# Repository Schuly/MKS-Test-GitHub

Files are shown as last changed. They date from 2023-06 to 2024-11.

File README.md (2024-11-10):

Inhaltsverzeichnis

# Inhaltsverzeichnis

1. **Hardware List**
    - [Motor](https://github.com/Schuly/MKS-Test-GitHub/tree/main/1%20Motorisierung)
    - [Platzhalter Unterpunkt 2](#)
2. **History**
    1. **Motorization**
        - [Platzhalter Unterpunkt 1](#)
        - [Platzhalter Unterpunkt 2](#)
    2. **Energy & Sensors**
        - [Platzhalter Unterpunkt 1](#)
        - [Platzhalter Unterpunkt 2](#)
    3. **Obstacle Race**
        - [Platzhalter Unterpunkt 1](#)
        - [Platzhalter Unterpunkt 2](#)
    4. **Photos**
        - [Platzhalter Unterpunkt 1](#)
        - [Platzhalter Unterpunkt 2](#)
    5. **Videos**
        - [Platzhalter Unterpunkt 1](#)
        - [Platzhalter Unterpunkt 2](#)
3. **.DS_Store**
4. **a. 3D Printing**
    - [Platzhalter Unterpunkt 1](#)
    - [Platzhalter Unterpunkt 2](#)
5. **b. Diagrams**
    - [Platzhalter Unterpunkt 1](#)
    - [Platzhalter Unterpunkt 2](#)
6. **c. Circuit Diagram**
    - [Platzhalter Unterpunkt 1](#)
    - [Platzhalter Unterpunkt 2](#)
7. **d. Code**
    - [Platzhalter Unterpunkt 1](#)
    - [Platzhalter Unterpunkt 2](#)
8. **e. Construction Manual**
    - [Platzhalter Unterpunkt 1](#)
    - [Platzhalter Unterpunkt 2](#)
9. **f. Other**
    - [Platzhalter Unterpunkt 1](#)
    - [Platzhalter Unterpunkt 2](#)

# Team MKS Robotics

**Infos zum Githubaufbau**

Unsere GitHub Dokumentation ist entsprechend dem Webertungsbogen der WRO Future Engineers Kategorie aufgebaut. Unter Punkt 1-5 sind die 
Informationen und das Material entsprechung der Bewertungskriterien vorhanden. 
Darunter under Punkt a-f findest man sonstige Sachen, die unsserer Meinung nach auch wichtig sind.

**Einleitung**

Wir sind Nico und Julian aus dem Saarland und nehmen dieses Jahr erneut für die Maximilian-Kolbe-Schule Wiebelskirchen an der WRO-Kategorie Future-Engineers teil. Im letzten Jahr haben wir bereits erfolgreich teilgenommen und den ersten Platz im Vorentscheid in Waldkirch/Freiburg belegt. Dadurch haben wir uns für das Deutschland-Finale in Chemnitz qualifiziert, wo wir den 4. Platz erreicht haben. Darüber hinaus haben wir bereits an vielen anderen Wettbewerben teilgenommen, darunter die "Robonight" in Saarbrücken, wo wir zweimal den zweiten Platz belegt haben, und die "make-it", wo wir den ersten Platz erreicht haben. Alles begann jedoch mit der WRO, bei der wir im Jahr 2019 in der Kategorie „Mission“ erstmals teilgenommen haben.

**Programmierung Eröffnungsrennen**

Beim diesjährigen Eröffnungsrennen verwenden wir die Grundidee vom letzten Jahr. Während der Fahrt misst der Roboter kontinuierlich die Werte der Ultraschallsensoren, die vorne, links und rechts angeordnet sind. Basierend auf den Werten des linken und rechten Sensors berechnet der Roboter den Mittelpunkt und steuert das autonome Auto proportional, um sich bestmöglich wieder in die Mitte zu bringen. Das bedeutet, je weiter das Auto von der Mitte entfernt ist, desto mehr lenkt es, um diese Mitte wieder zu erreichen.

Ein Beispiel: linker Ultraschallsensor: 10, rechter Ultraschallsensor: 50. Hier zeigt der linke Sensor eine sehr kurze Entfernung, was bedeutet, dass das Auto ziemlich weit links an der Bande ist. Wenn wir nun die Summe der beiden Werte nehmen, ergibt sich die Zahl 60. Die Hälfte davon ist 30. Wenn beide Sensoren nun den Wert 30 ausgeben, wissen wir, dass der Roboter genau in der Mitte ist. Um diese Mitte zu erreichen, berechnen wir den Prozentanteil und lenken entsprechend.

Da dieser Prozess sehr schnell und sehr oft wiederholt wird, kann es manchmal zu einem leichten Schwanken kommen, das das Auto aber ausgleicht. Um am Ende der 3 Runden perfekt zu stoppen, zählt das Auto eine Variable hoch, wenn es eine Kurve fährt. Wir erkennen eine Kurve, wenn plötzlich ein Sensor einen sehr hohen Wert misst. Wenn wir also wie im Beispiel eine Summe von 60 haben und einer der Sensoren plötzlich 150 misst, können wir sicher sein, dass wir uns in einer Kurve befinden. Wenn der Roboter dies 12-mal erkannt hat, bleibt das Auto im richtigen Abschnitt stehen.

**Programmierung Hindernisrennen**

Bei dem Hindernisrennen nutzen wir als Grundlage die Programmierung von dem Eröffnungsrenenn. Denn hier müssen wir ja auch autonom fahren. Nur wenn die Kamera hier einen bunten Stein erkennt, weichen wir aus. Bei roten Steinen rechtsrum, bei Grünen linksherum. Für die Farberkennung haben wir Filter/Masken, damit wir nur die Farben sehen und die sonstigen Fehler, die die Kamera erkennen könnte, ausblenden. Des Weiteren verändern wir die Belichtung des Bildes dynamisch je nach Umgebungshelligkeit, damit wir die Fraben besser erkennen können.

**Technische Komponenten**

Raspberry Pi 4
3x HC-SR04 Ultraschallsensoren
Motor
Motorsteuerung
18V Bosch Bohrmaschinen-Akku
Spannungswandler von 18V zu 5V
Knopf
Schalter
Led-Lampe
JumperKabel / sonstige Kabel
Pi-Cam
Verschiedene Widerstände
Servo-Motor (mg996r)

**Sonstige Komponenten**

Metall Grundplatte
Metall Schraubstützen
Selbst modellierte 3D-Modelle aus dem 3D-Drucker
Verschiedene Schrauben
Kabelbinder
Heißkleber / Sekundenkleber
Schrumpfschläuche
Platine für Ultraschallsensoren

Um eine Tabelle wie die beschriebene auf GitHub darzustellen, kannst du Markdown verwenden. GitHub unterstützt Markdown-Tabellen, die einfach formatiert und leicht lesbar sind. Hier ist die entsprechende Markdown-Syntax für die Tabelle, die du erstellen möchtest:

markdown
Code kopieren
# 🤖 Hardware 🤖

## ⚙️ Components ⚙️

| Name | Product | Price |
|---|---|---|
| **RC Car** | Carisma GT24 | $263  |
| **RC Car Battery** | Gens Ace 1300mAh Battery | $35 |
| **Drive Motor & ESC** | Furitek Komodo Motor + Lizard Pro ESC | $226  |
| **Turning Motor**  | Hitec HS-5055MG Servo Motor | $38 |
| **Motor Mount** | GT24 High Performance Alloy Motor Mount | $17 |
| **CSI Camera** | SainSmart Wide Angle Fish-Eye Camera | $19 |
| **Raspberry Pi HAT** | HiWonder TurboPi HAT | $61 |
| **Raspberry Pi** | Vemico Raspberry Pi 4 | $176  |
| **Raspberry Pi Fan** | GeeekPi Fan | $19 |
| **ON/OFF Switch**  | DaierTek Switch | $13 |

**Total Car Cost:** $867 CAD

---

*3D printed parts were made with the BambuLab P1P*

# ⚙️ Hardware & Components ⚙️

| Category | Component | Quantity | Price |
|---|---|---|---|
| **Computing** | Raspberry Pi 4 | 2 | |
| | Arduino Nano | 1 | |
| | Raspberry Pi 3 | 1 | |
| **Sensors** | HC-SR04 Ultrasonic Sensor | 3 | |
| **Motors** | Brushless Motor 12V | 1 | |
| | Servo Motor (MG996R) | 1 | |
| **Motor Control**  | Motor Controller (L298N) | 1 | |
| **Power** | 18V Bosch Drill Battery | 1 | |
| | Voltage Converter (18V to 5V) | 1 | |
| **Controls** | Button | 1 | |
| | Switch | 1 | |
| | LED Lamps | 2 | |
| **Connectivity** | Jumper Wires / Other Cables | Various  | |
| | USB Webcam (Logitech Brio 500) | 1 | |

### 🛠️ Other Components:

- **Metal Baseplate**
- **Metal Standoffs**
- **Self-modeled 3D Prints from a 3D Printer**
- **Various Screws**
- **Cable Ties**
- **Hot Glue / Super Glue / Metal Glue**
- **Heat Shrink Tubing**

---

**Total Cost:** (Bitte hier Gesamtkosten eintragen)

*Hinweis: Einige der Komponenten sind 3D-gedruckt und selbst modelliert.*

# ⚙️ Hardware & Components ⚙️

| Quantity | Component | Price per Unit | Total Price | Product Link |
|---|---|---|---|---|
| 2 | [Raspberry Pi 4](#) | €X.XX | €XX.XX | [Link](#) |
| 1 | [Arduino Nano](#) | €X.XX | €X.XX | [Link](#) |
| 1 | [Raspberry Pi 3](#) | €X.XX | €X.XX | [Link](#) |
| 3 | [HC-SR04 Ultrasonic Sensor](#) | €X.XX | €XX.XX | [Link](#) |
| 1 | [Brushless Motor 12V](#) | €X.XX | €X.XX | [Link](#) |
| 1 | [Servo Motor (MG996R)](#) | €X.XX | €X.XX | [Link](#) |
| 1 | [Motor Controller (L298N)](#) | €X.XX | €X.XX | [Link](#) |
| 1 | [18V Bosch Drill Battery](#) | €X.XX | €X.XX | [Link](#) |
| 1 | [Voltage Converter (18V to 5V)](#) | €X.XX | €X.XX | [Link](#) |
| 1 | [Button](#) | €X.XX | €X.XX | [Link](#) |
| 1 | [Switch](#) | €X.XX | €X.XX | [Link](#) |
| 2 | [LED Lamps](#) | €X.XX | €XX.XX | [Link](#) |
| Various  | [Jumper Wires / Other Cables](#) | €X.XX | €X.XX | [Link](#) |
| 1 | [USB Webcam (Logitech Brio 500)](#) | €X.XX | €X.XX | [Link](#) |

### 🛠️ Other Components:

- **Metal Baseplate**
- **Metal Standoffs**
- **Self-modeled 3D Prints from a 3D Printer**
- **Various Screws**
- **Cable Ties**
- **Hot Glue / Super Glue / Metal Glue**
- **Heat Shrink Tubing**

---

**Total Cost:** €X.XX (Bitte hier Gesamtkosten eintragen)

*Hinweis: Einige der Komponenten sind 3D-gedruckt und selbst modelliert.*

# ⚙️ Hardware & Components ⚙️

| Quantity | Component | Price per Unit | Total Price |
|---|---|---|---|
| 2 | [Raspberry Pi 4](https://www.amazon.com/-/de/dp/B0899VXM8F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) | $86 | $172 |
| 1 | [Arduino Nano](https://www.amazon.com/-/de/dp/B0DFGR288F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) | $8 | $8 |
| 1 | [Gyro Sensor](https://www.amazon.com/-/de/dp/B07MMZ37PT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) | $5 | $5 |
| 1 | [Color Sensor](https://www.amazon.com/-/de/dp/B087Z3K6P5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) | $4 | $4 |
| 3 | [HC-SR04 Ultrasonic Sensor](https://www.amazon.com/-/de/dp/B0BDFLPZ2R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) | $4 | $12 |
| 1 | [Brushless Motor 12V](https://www.amazon.com/-/de/dp/B07D297L9F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) | $14 | $14 |
| 1 | [Servo Motor (A81BHP)](https://www.vgr-technology.de/p/agf-rc-servo-a81bhp-hochgeschwindigkeitslenkung-rc-servomotor-0-052-sec-23kg-programmierbar) | $95 | $95 |
| 1 | [Servo Motor small](https://www.amazon.com/-/de/dp/B0BKPL2Y21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) | $3 | $3 |
| 1 | [Motor Controller (L298N)](https://www.amazon.com/-/de/dp/B0CR6BX5QL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) | €X.XX | €X.XX |
| 1 | [18V Bosch Drill Battery](https://www.bosch-professional.com/de/de/products/gba-18v-2-0ah-1600Z00036) | $65 | $65 |
| 1 | [Voltage Converter (18V to 5V)](https://www.joy-it.net/de/products/SBC-Buck03](https://www.reichelt.de/de/de/entwicklerboards-spannungsregler-dc-dc-wandler-debo-dcdc-down-7-p333858.html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)) | $20 | $20 |
| 1 | [Button](https://www.amazon.com/-/de/dp/B08SQHRRDH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) | $2 | $2 |
| 1 | [Switch](https://www.amazon.com/-/de/dp/B00004WLKC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) | $8 | $8 |
| 2 | [LED Lamps](https://www.amazon.com/-/de/dp/B0BXKM8PN3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) | $1 | $2 |
| Various  | [Jumper Wires / Other Cables](https://www.amazon.com/-/de/dp/B01EV70C78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) | €X.XX | €X.XX |
| 1 | [USB Webcam (Logitech Brio 500)](https://www.amazon.com/-/de/dp/B0CPBD3PDD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) | $84 | $84 |

---

### 🛠️ Other Components:

| Component | Price |
|---|---|
| [Metal Baseplate / Chassi](https://funduinoshop.com/diy-werkstatt/bausaetze/chassis/yfrobot-chassis-kit-mit-lenkachse)  | $50 |
| [Metal Standoffs](https://www.amazon.com/-/de/dp/B06Y5TJXY1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)  | $15 |
| [Self-modeled 3D Prints from a 3D Printer](https://www.amazon.com/-/de/dp/B0D421Q2Q2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) | $13 |
| [Various Screws](https://www.amazon.com/-/de/dp/B0BMQFHDBH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) | &10 |
| [Cable Ties](https://www.amazon.com/-/de/dp/B08TVLYB3Q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) | $5 |
| [Hot Glue / Super Glue / Metal Glue](https://www.amazon.com/-/de/dp/B09XY1WDTX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) | $10 |
| [Heat Shrink Tubing](https://www.amazon.com/-/de/dp/B0BG6V4HV4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) | $5 | 

---

**Total Cost:** €X.XX (Bitte hier Gesamtkosten eintragen)

*Hinweis: Einige der Komponenten sind 3D-gedruckt und selbst modelliert.*

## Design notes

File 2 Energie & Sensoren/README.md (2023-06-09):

**Energie**

Unser Auto wird mit einem handelsüblichen 18V Bosch Akku betrieben. Dieser Akku wird in einen Akku-Slot eingeschoben. Von dort aus führt eine Verbindung zum Spannungswandler. Der Wandler wandelt die Spannung auf 5V um, die wir für die Raspberry Pis benötigen. Zusätzlich verwenden wir eine Motorsteuerung, die direkt mit 18V versorgt wird. Es ist erwähnenswert, dass die Ultraschallsensoren mit 5V betrieben werden, während andere Sensoren wie der Farbsensor oder der Gyrosensor mit 3,3V arbeiten.

**Sensoren**

In unserem Auto sind eine Vielzahl von Sensoren verbaut. Zum einen haben wir drei HCSR-04 Sensoren integriert, die zur Erkennung der Fahrbahn und zum entsprechenden Lenken verwendet werden. Des Weiteren haben wir einen Farbsensor installiert, der die orangenen und blauen Linien erkennt und somit die Runden zählt, damit wir nach drei Runden erfolgreich stoppen können. Außerdem haben wir einen Gyrosensor eingebaut, um eine zu starke Drehung zu vermeiden. Ganz oben befindet sich zudem eine Kamera. Es handelt sich um eine USB-Webcam von Logitech, die für die Hinderniserkennung verwendet wird.

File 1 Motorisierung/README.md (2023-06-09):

**Motorisierung**

Beim letztjährigen Future Engineers Wettbewerb haben wir auf Fischertechnik-Teile gesetzt. Dieses Jahr wollten wir das ändern. Stattdessen nutzen wir im Deutschlandfinale unser komplett selbstgebautes Auto, das wir größtenteils auch im Vorentscheid verwendet haben.
Dafür haben wir als Grundlage ein Funduino-Kit genutzt, das speziell für Future Engineers entwickelt wurde. Von diesem Kit haben wir jedoch nur die Grundplatten und die Distanzhülsen verwendet. In der Bauanleitung („e Bauanleitung“) findet man die genauen Maße und Abmessungen der Platten, Schrauben und aller weiteren Komponenten.

**Lenkung**

Für die Lenkung nutzen wir einen 20kg-Servolenkungsmotor. Dieser Motor liegt quer auf unserer Grundplatte. Von dem Gewinde des Servos führt eine kleine Stange, die mit Schrauben befestigt ist, zur eigentlichen Lenkachse. Diese Lenkachse verbindet die beiden Vorderräder miteinander. Wenn der Servo in eine Richtung lenkt, wird die Lenkachse als Ganzes verschoben, und somit auch die Räder.

**Antriebsmotor**

Als Antriebsmotor verwenden wir einen herkömmlichen Motor, der über die Motorsteuerung "L298N" betrieben wird. An diese Motorsteuerung werden direkt 18V vom Akku angeschlossen. Der Motor wird ebenfalls darüber betrieben. Vom Motor gehen noch drei Kabel ab, die wir zur Steuerung des Motors nutzen und die direkt in den "Lenk- und Fahr-Raspberry Pi" führen. Um beide Räder gleichzeitig antreiben zu können, verwenden wir eine Zahnradübersetzung, die die Motorumdrehungen auf ein Zahnrad überträgt, das fest an der Antriebsachse angebracht ist.

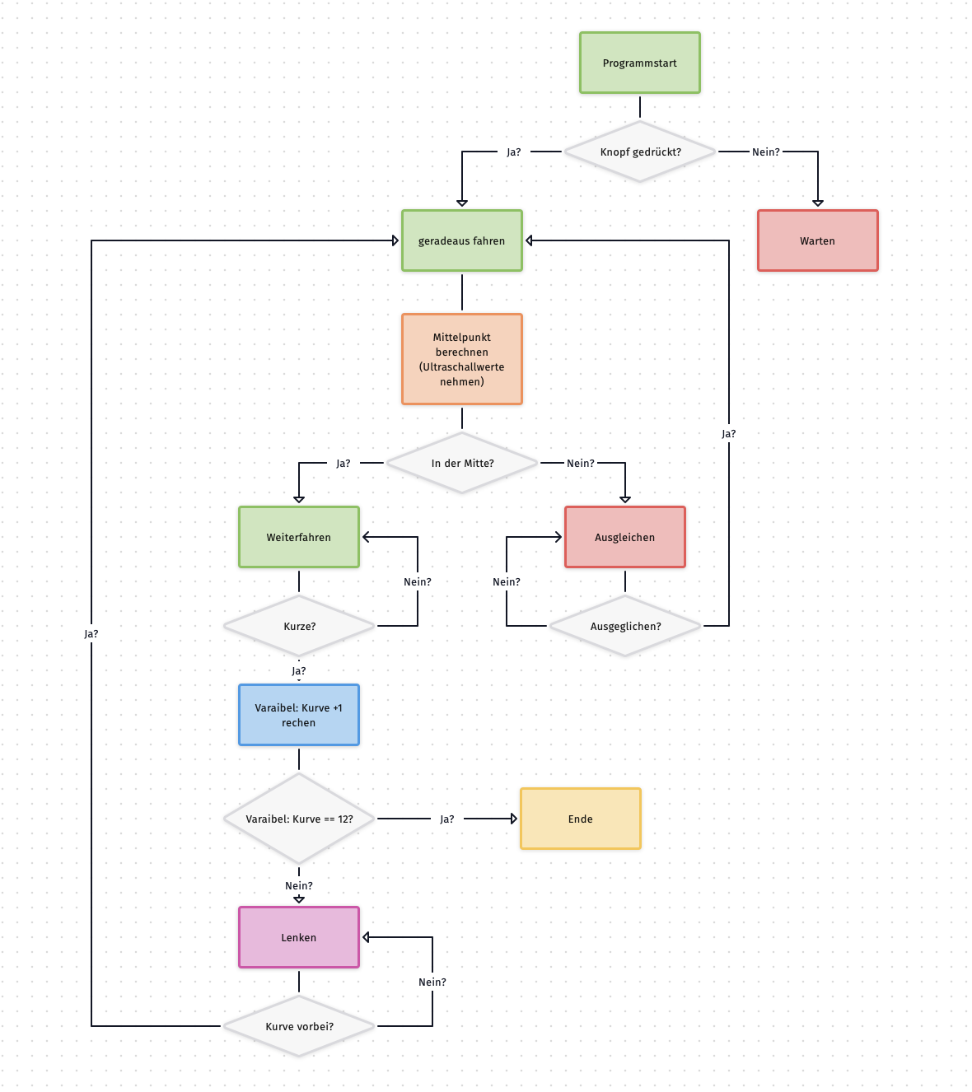
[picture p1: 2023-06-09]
b Diagramme/Eröffnungsrennen.jpg

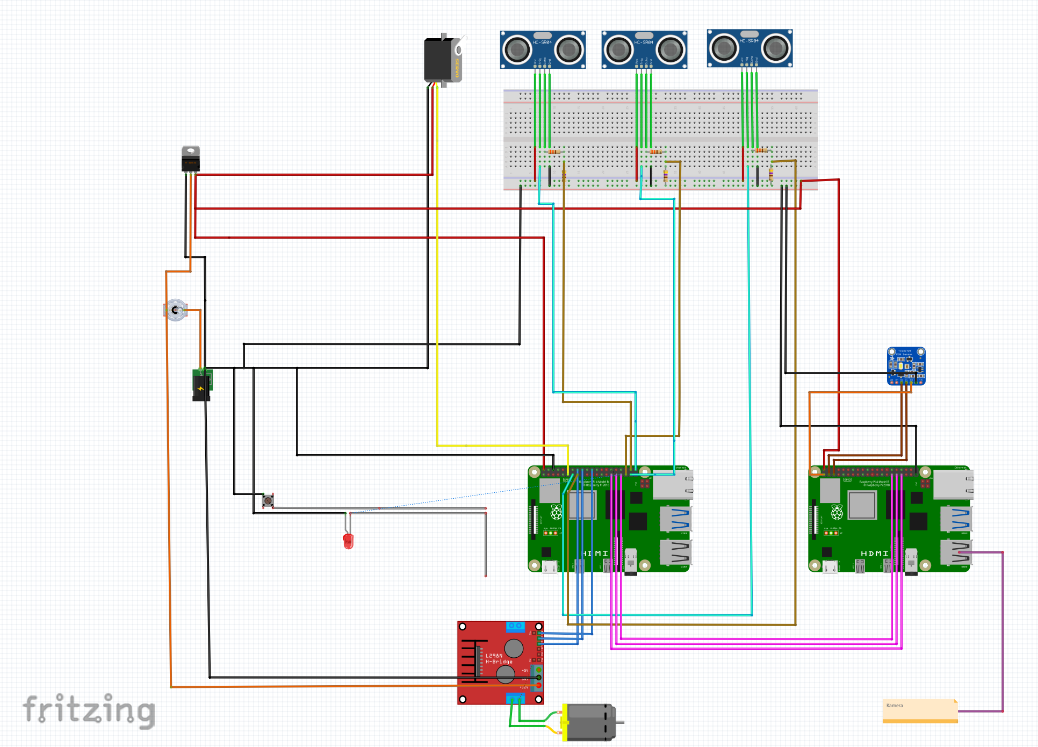
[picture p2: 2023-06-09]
c Schaltplan/Steckplatine.jpg

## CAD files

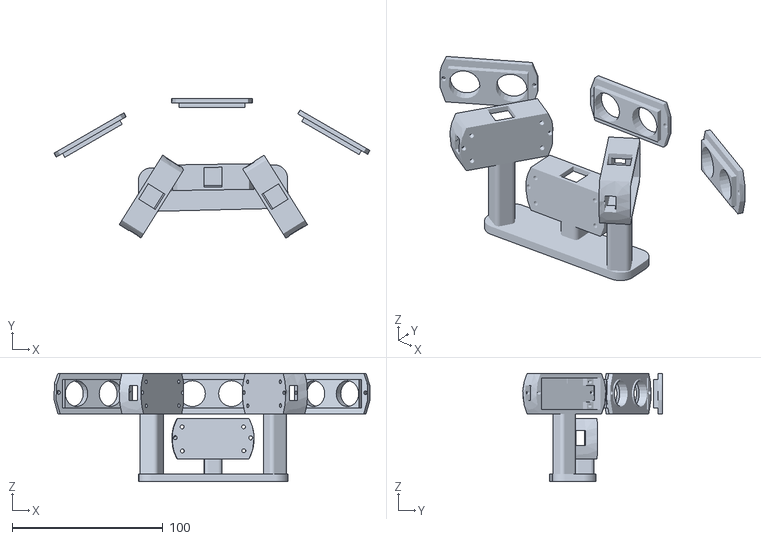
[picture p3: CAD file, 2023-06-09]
a 3D Druck/Ultraschallhalter.stl
209.9 x 92.7 x 72.0

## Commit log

2023-06-09 Update and rename test to Motorisierung
2023-06-09 Create Energie & Sensoren.md
2023-06-09 Update Energie & Sensoren.md
2023-06-09 Rename Energie & Sensoren.md to README.md
